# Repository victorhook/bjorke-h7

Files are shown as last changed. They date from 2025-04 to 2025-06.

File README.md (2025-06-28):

# 🛩️ Bjorke H7 Flight Controller

Bjorke H7 is a fully open source high-performance, ArduPilot-compatible flight controller built around the powerful STM32H743VIT6 MCU. Designed for flexibility and reliability, it supports a wide range of applications—from autonomous drones to experimental robotics.

---

## 🔧 Key Features

### ⚙️ Processing Power
- **MCU**: STM32H743VIT6 (480 MHz, 2MB Flash, 1MB RAM)

### 🧭 Sensors
- **IMU**: ICM-42688-P – ultra-low noise 6-axis motion tracking
- **Barometer**: BMP388 – high-accuracy altimeter for reliable altitude estimation

### 🔄 Interfaces & I/O
- **8x Motor Outputs** via 2x ESC 8-pin JST connectors
- **8x UARTs** for telemetry, GPS, companion computers, etc.
- **1x I²C** for external sensors or peripherals
- **3x Servo Outputs** + **1x dedicated GPIO**
- **1x RGB Status LED**
- **2x extra ADC Input Pins** for external sensors
- **1x CAN** (with onboard TJA1051TK/3 transceiver) – plug-and-play UAVCAN support

### 💾 Storage & Logging
- **MicroSD card slot** for robust onboard logging

### 🔌 Power Architecture
- **5V @ 3A** DC-DC
- **3.3V @ 3A** DC-DC

---

## ⚡ Designed for ArduPilot
Bjorke H7 runs **ArduPilot firmware** with support for:
- Real-time telemetry
- In-flight parameter updates
- MAVLink compatibility
- Full hardware-in-the-loop (HITL) testing
- CAN-based peripherals (UAVCAN GPS, ESCs, etc.)

---

## 🚧 Status
- [X] PCB rev.A designed and ordered
- [X] hwdef.dat
- [X] PCB rev.A hardware validated
- [X] Initial bring-up with ArduPilot firmware
- [X] Lua scripting verified
- [ ] First takeoff achieved
- [ ] 1 hour flight time achieved
- [ ] 5 hours flight time achieved
- [ ] 10 hours flight time achieved
- [ ] 25 hours flight time achieved
- [ ] 50 hours flight time achieved
- [ ] 100 hours flight time achieved

---

## 🧪 Ideal for:
- Custom drones (quads, hexas, octos)
- Research platforms
- Robotics
- Developers who need **max control and visibility**

## Flashing
With a fresh board we must flash the ardupilot bootloader. This requires us to put the mcu in DFU mode, which is done by holding down the boot button while powering on the board.

### Ardupilot + bootloader
1. Hold down boot button while powering on the board. If you're on linux you can use `dmesg -w` to monitor usb acitivty and you should get something like `Product: DFU in FS Mode` show up.
2. Open STM32CubeProgrammer and connect with USB
3. Open the file in `binaries/arducopter_with_bl.hex` and press flash
4. Powercycle the board and you should see `bjorke-BL` registers itself as USB device at first, then once it leaves bootloader you should get `bjorke` as USB device, and a serial port, eg `/dev/ttyACM0`

### Ardupilot application only
1. Using the `uploader.py` in AP repo
    ```
    python3 Tools/scripts/uploader.py build/bjorke/bin/arducopter.apj
    ```
2. Or, after built in repo: 
    ```
    ./waf copter --upload
    ```

### Ardupilot bootloader only
1. Put into DFU (same as above)
2. Flash bootloader using either STM32CubeProgrammer, or `dfu-util` with:
    ```
    dfu-util -a 0 --dfuse-address 0x08000000 -D binaries/AP_Bootloader.bin -R
    ```

### Building the code
Enter the ardupilot repository and run:

#### Bootloader
Either using:
```
./Tools/scripts/build_bootloaders.py bjorke
```
Creates binaries in `Tools/bootloaders/`:
- `Tools/bootloaders/bjorke_bl.bin`
- `Tools/bootloaders/bjorke_bl.hex`

Or, using:
```
./waf configure --board bjorke --bootloader
./waf clean
./waf bootloader
```

Bootloader binaries should be built to `build/bjorke/bin`
- AP_Bootloader.apj
- AP_Bootloader.bin
- AP_Bootloader.hex

#### Application
For the application build we first must have built bootloader with `./Tools/scripts/build_bootloaders.py`.
This is because AP tooling seems to expect a bootloader binary in `Tools/bootloaders/`.

```
./waf configure --board bjorke
./waf copter
```

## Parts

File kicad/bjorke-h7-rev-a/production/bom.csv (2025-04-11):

Designator | Footprint | Quantity | Value | LCSC Part #
C1 | 0402 | 1 | 4.7uF
C10, C12, C13, C19, C2, C20, C21, C23, C24, C28, C3, C32, C37, C5, C7, C8 | 0402 | 16 | 0.1uF
C11, C18, C9 | 0402 | 3 | 2.2uF
C14, C15, C34, C35 | 0805 | 4 | 10uF | C440198
C16, C36 | 0402 | 2 | 0.1uF | C307331
C17, C33, C38 | 0805 | 3 | 47uF | C16780
C22 | 0402 | 1 | 10nF
C39, C40 | 0402 | 2 | 15pF | C1548
C4, C6 | 0402 | 2 | 15pF
Card1 | TF-SMD_TF-021B-H265 | 1 | TF PUSH | C498185
D1 | 0603 | 1 | YELLOW
D2 | 0603 | 1 | BLUE
D3 | 0603 | 1 | GREEN
D4, D5, D7, D8 | D_SOD-323 | 4 | 30V 450mA | C2762697
D6 | 0603 | 1 | RED
J1 | Conn_2_Accesory_Bigger | 1 | Power_3V3
J10 | Conn_4_Accesory_Bigger | 1 | Servo 1-2
J11 | Conn_4_Accesory_Bigger | 1 | USART6
J12 | Conn_4_Accesory_Bigger | 1 | I2C
J13 | Conn_4_Accesory_Bigger_2x2 | 1 | UART8
J14 | Conn_3_2.54_SMD | 1 | Debug
J15 | Conn_3_Accesory_Bigger | 1 | RGB
J16 | CONN-TH_SM08B-SRSS-TB-LF-SN | 1 | FC-ESC 1 JST
J17 | Conn_4_Accesory_Bigger | 1 | UART5
J18 | CONN-TH_SM08B-SRSS-TB-LF-SN | 1 | FC-ESC 2 JST
J19 | Conn_8_Accesory | 1 | FC-ESC 2 Solder Pads Back
J2 | Conn_2_Accesory_Bigger | 1 | Power_5V
J20 | Conn_4_Accesory_Bigger | 1 | CAN
J21 | Conn_2_Accesory_Bigger | 1 | Power_VBAT
J22 | Conn_4_Accesory_Bigger | 1 | Servo5-GPIO1
J23, J24 | Conn_8_Accesory | 2 | FC-ESC 1 Solder Pads Front
J25 | Conn_3_Accesory_Bigger | 1 | Analog In
J26 | Conn_4_Accesory_Bigger | 1 | UART7
J3 | Conn_4_Accesory_Bigger | 1 | USART3
J4 | Conn_2_Accesory_Bigger | 1 | Power_4V5
J5 | Conn_8_Accesory | 1 | FC-ESC 1 Solder Pads Back
J6 | Conn_4_Accesory_Bigger_2x2 | 1 | USART2
J7 | Conn_4_Accesory_Bigger | 1 | USART1
J8 | Conn_4_Accesory_Bigger | 1 | Servo 3-4
J9 | Conn_4_Accesory_Bigger | 1 | UART4
L3, L4 | IND-SMD_L5.7-W5.2 | 2 | 6.8uH | C7461350
R10, R18, R6, R7, R8 | 0402 | 5 | 1k
R11, R2 | 0402 | 2 | 5.1k
R12, R13, R14, R15, R3, R4, R5, R9 | 0402 | 8 | 10k
R16 | 0402 | 1 | 120R
R17, R20, R21, R22 | 0402 | 4 | 2.2k
R23 | 0402 | 1 | 51k | C25794
R24, R26 | 0402 | 2 | 10k | C25744
R25 | 0402 | 1 | 30.9k | C185428
SW1 | SW-SMD_TS-1086EV-16 | 1 | SW_SPST
U2 | LQFP-100_14x14mm_P0.5mm | 1 | STM32H743VIT6
U3 | USB-SMD_GT-USB-7010AN | 1 | GT-USB-7010AN | C963370
U5 | SENSORM-SMD_BMP388 | 1 | BMP388 | C779278
U6 | LGA-14_L3.0-W2.5-P0.50-TL | 1 | ICM-42688-P | C1850418
U7 | HVSON-8-1EP_3x3mm_P0.65mm_EP1.6x2.4mm | 1 | TJA1051TK-3 | C2875699
U8, U9 | SOT-583-8_L2.1-W1.2-P0.50-LS1.6-BL | 2 | TPS563300DRLR | C5219249
Y1 | Crystal_SMD_2016-4Pin_2.0x1.6mm | 1 | 16 MHz | C2965579

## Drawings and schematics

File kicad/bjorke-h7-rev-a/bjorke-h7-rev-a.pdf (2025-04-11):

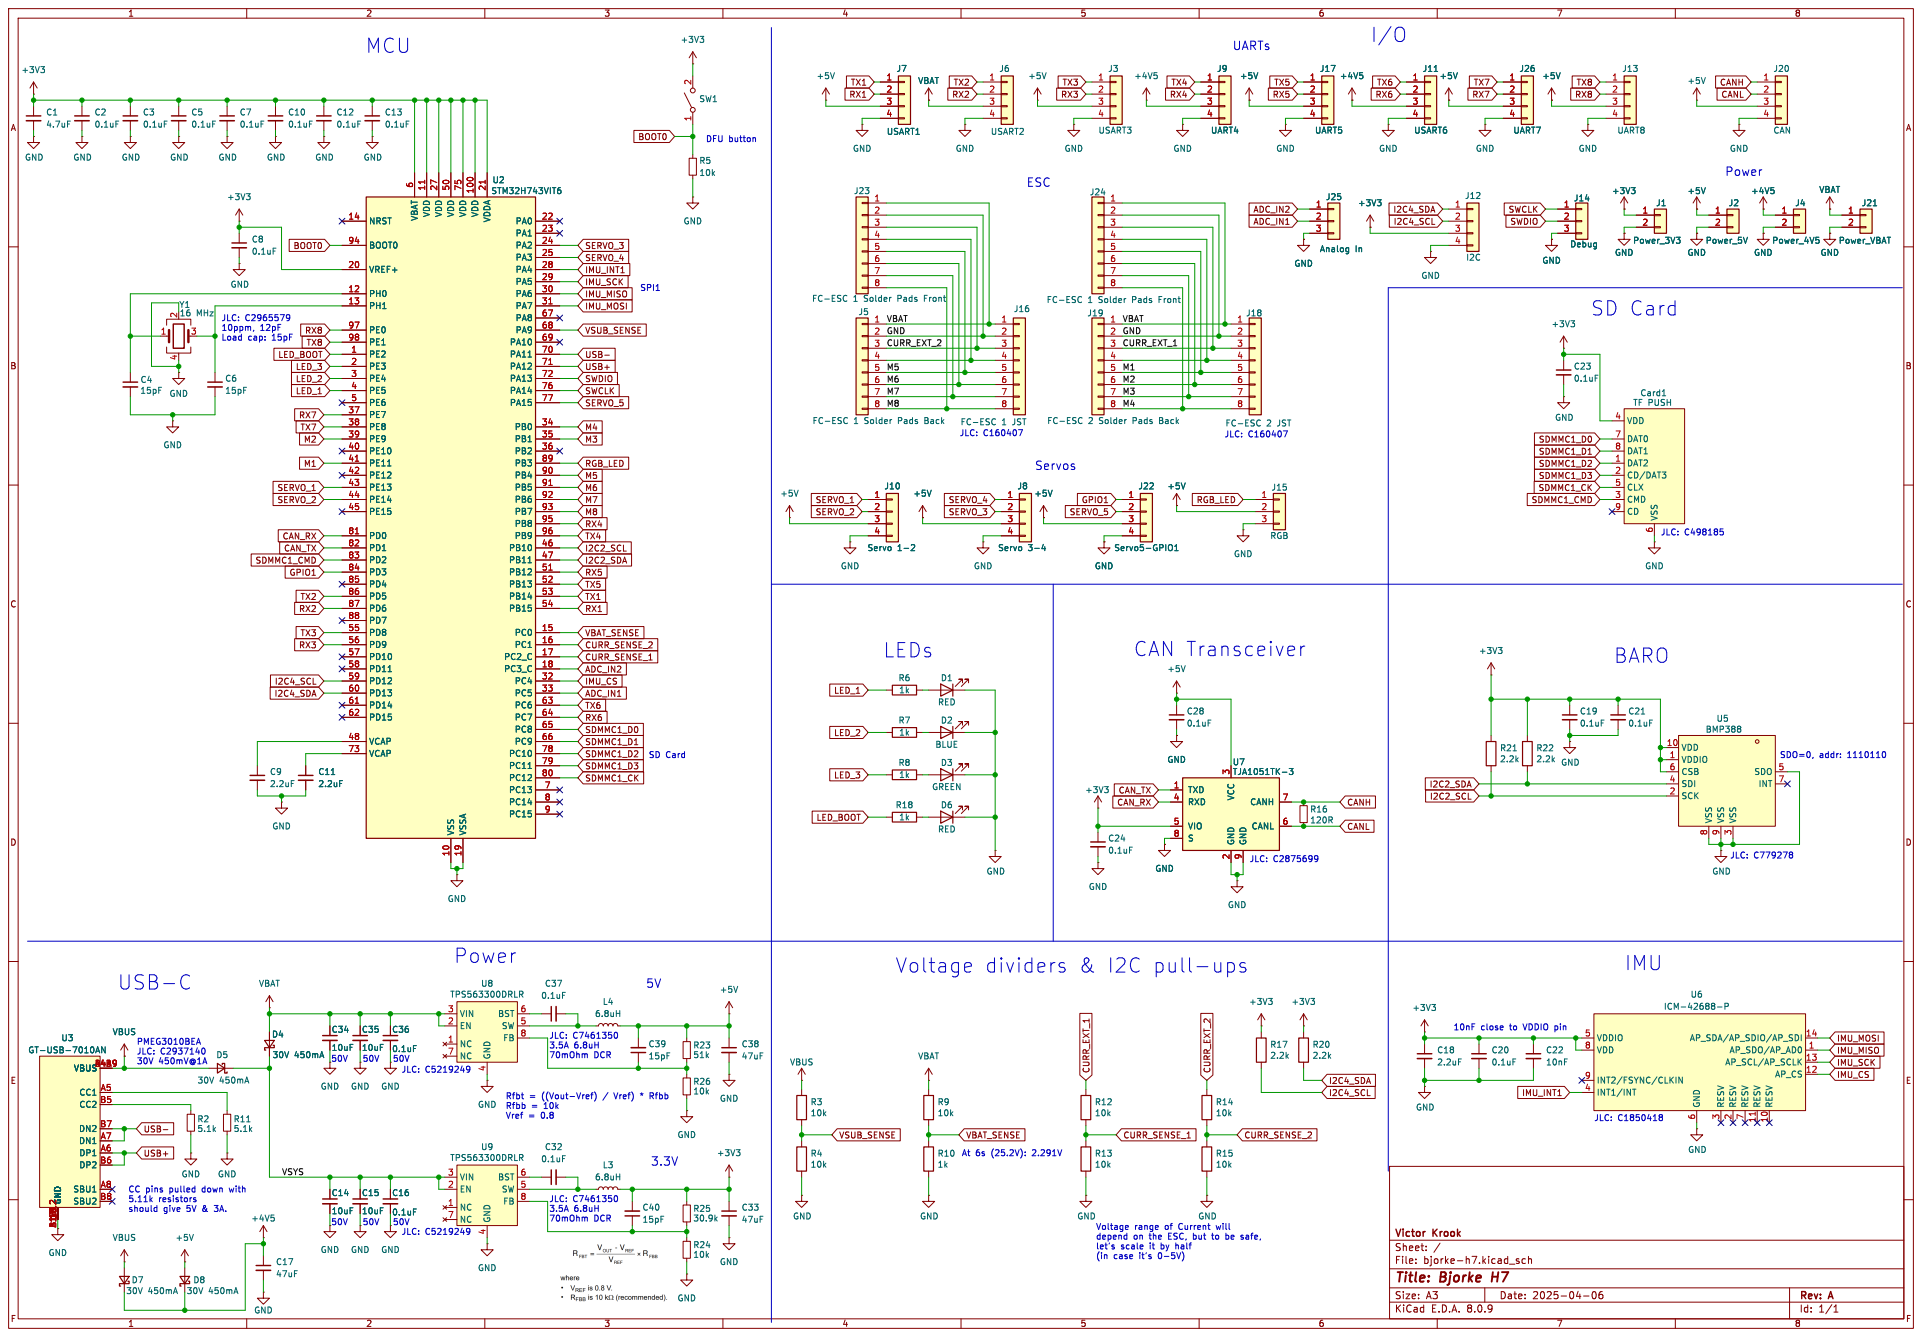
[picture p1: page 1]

J18 FC-ESC 2 JST GND

J24 FC-ESC 1 Solder Pads Front C2
0.1uF GND

J23 FC-ESC 1 Solder Pads Front 1

J19 FC-ESC 2 Solder Pads Back GND

J16 FC-ESC 1 JST GND

3 RXD 4 VIO 5 CANL 6 CANH 7 S

Voltage dividers & I2C pull-ups

4 SW 5 BST 6 FB 8 NC 1 NC 7 U8 TPS563300DRLR GND
+3V3 GND

10nF close to VDDIO pin

JLC: C1850418 CC pins pulled down with

4 SW 5 BST 6 FB 8 NC 1 NC 7 U9 TPS563300DRLR

GND
Voltage range of Current will depend on the ESC, but to be safe,

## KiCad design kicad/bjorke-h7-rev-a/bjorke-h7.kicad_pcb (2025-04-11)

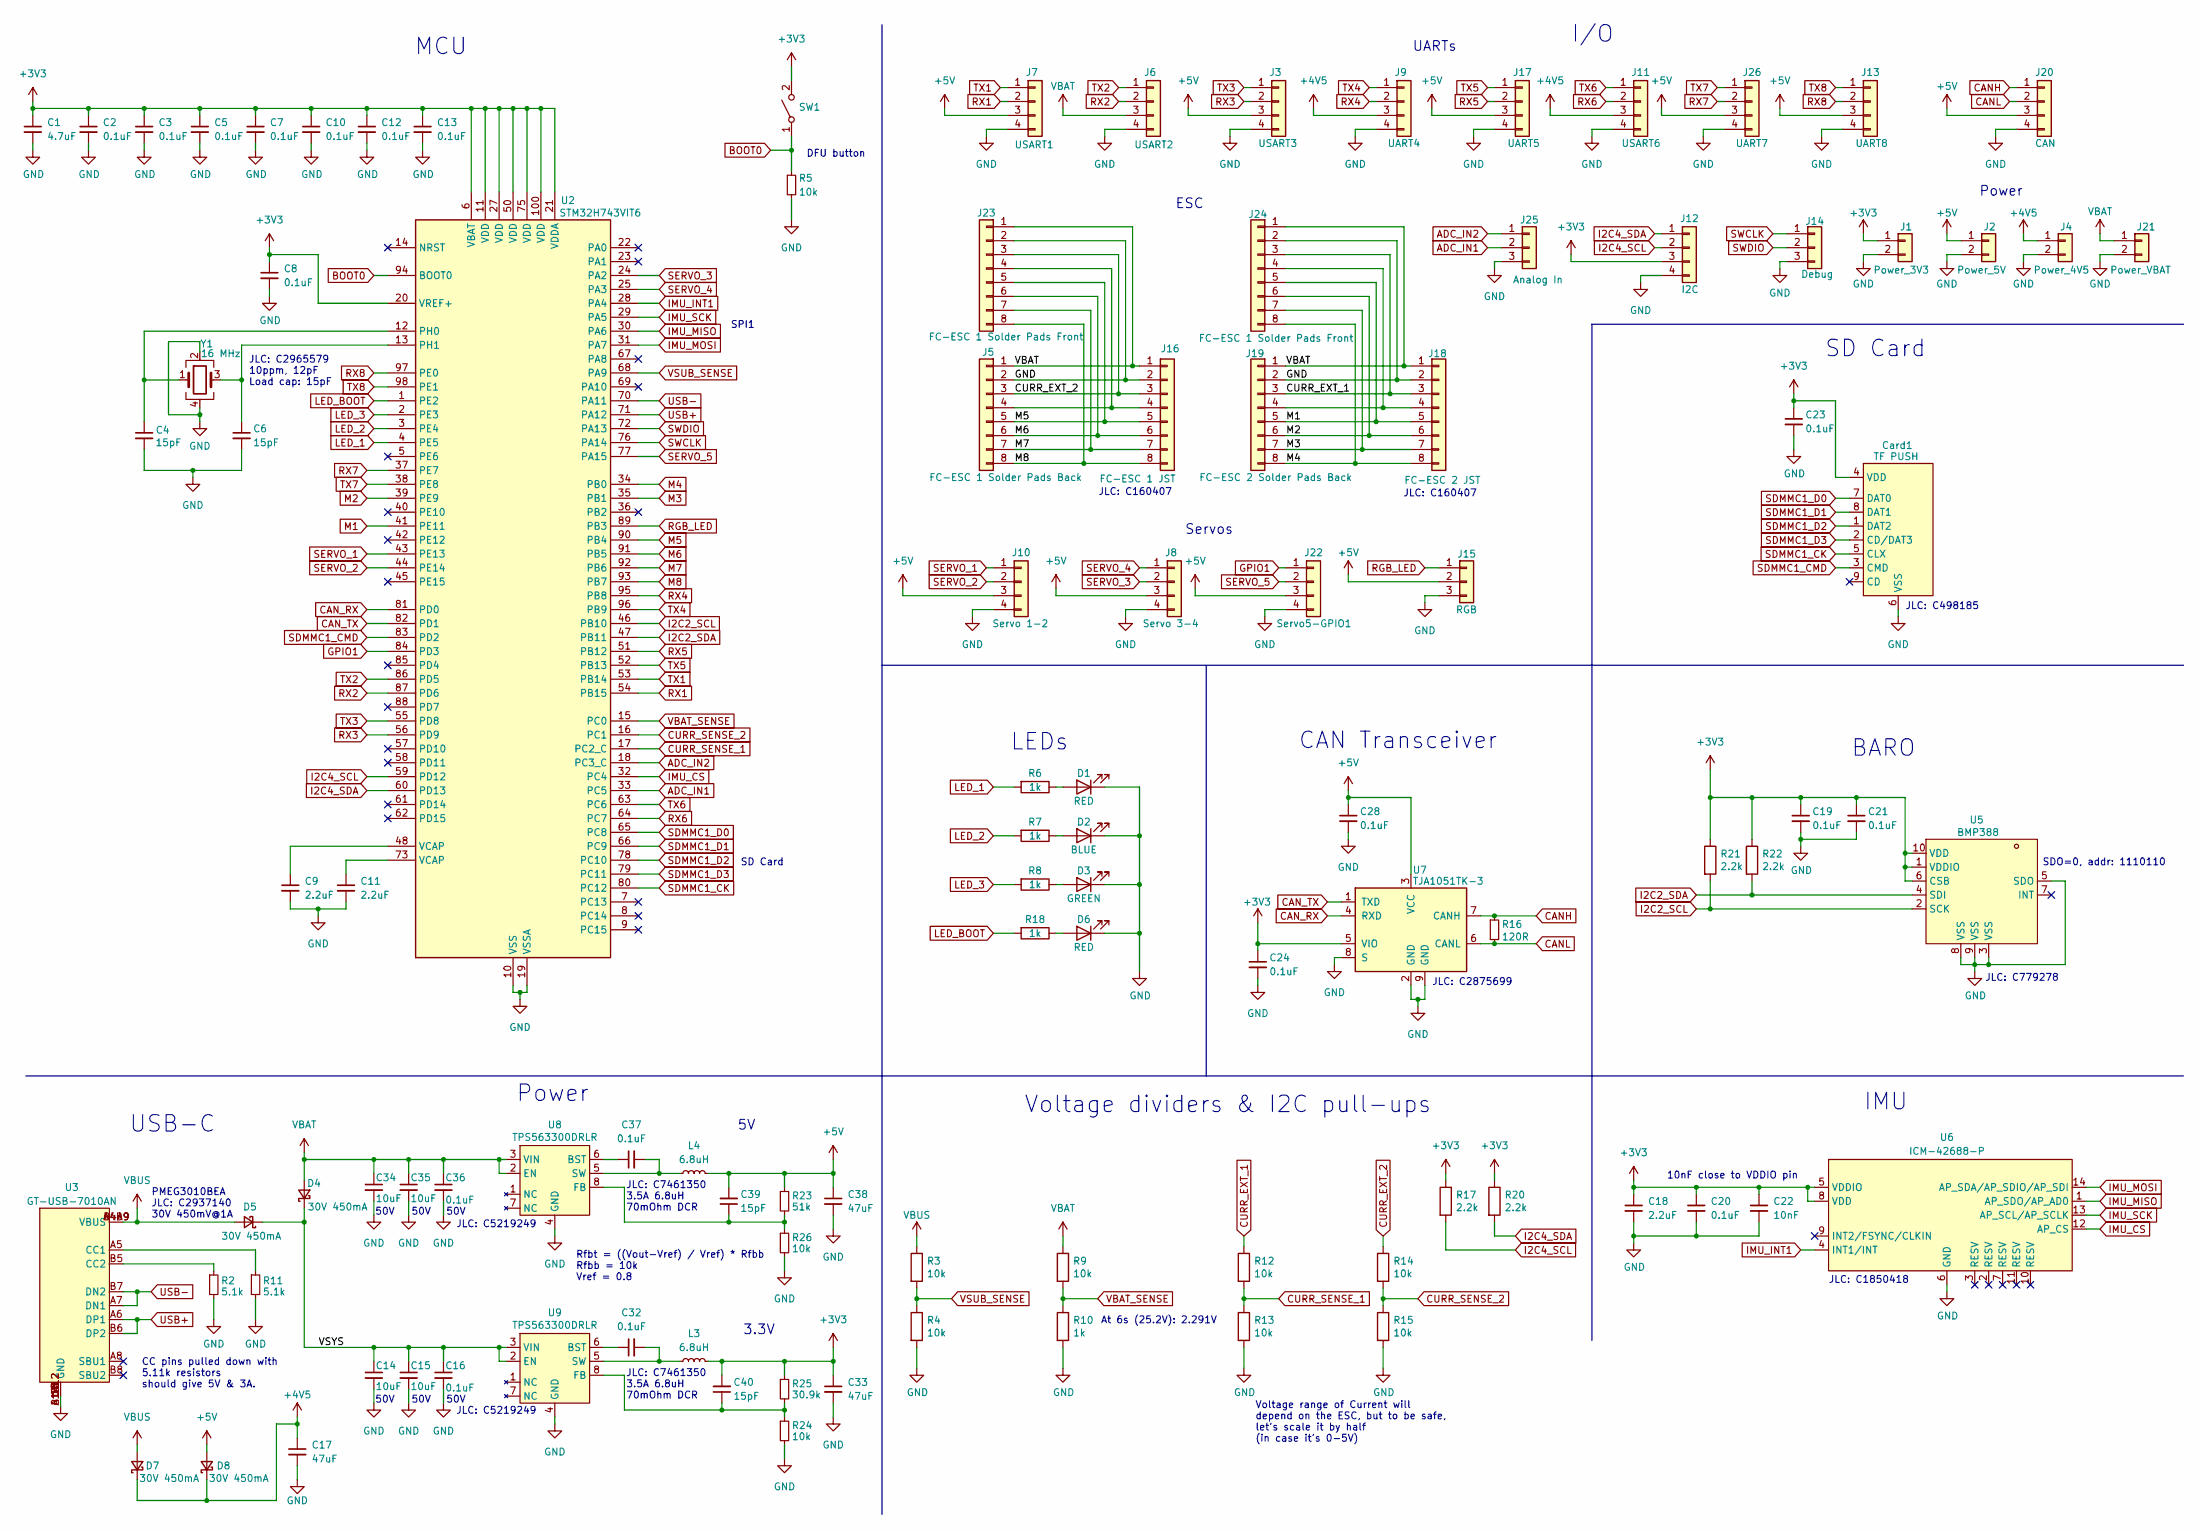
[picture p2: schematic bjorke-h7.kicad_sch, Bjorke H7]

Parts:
C1: 4.7uF; C_0402_1005Metric
C2, C3, C5, C7, C8, C10, C12, C13, C19, C20, C21, C23, C24, C28, C32, C37: 0.1uF; C_0402_1005Metric
C4, C6: 15pF; C_0402_1005Metric
C9, C11, C18: 2.2uF; C_0402_1005Metric
C14, C15, C34, C35: 10uF; C_0805_2012Metric; LCSC Part C440198
C16, C36: 0.1uF; C_0402_1005Metric; LCSC Part C307331
C17, C33, C38: 47uF; C_0805_2012Metric; LCSC Part C16780
C22: 10nF; C_0402_1005Metric
C39, C40: 15pF; C_0402_1005Metric; LCSC Part C1548
Card1: TF PUSH; TF-SMD_TF-021B-H265; LCSC Part C498185
D1, D6: RED; LED_0603_1608Metric
D2: BLUE; LED_0603_1608Metric
D3: GREEN; LED_0603_1608Metric
D4, D5, D7, D8: 30V 450mA; D_SOD-323; LCSC Part C2937140
J1: Power_3V3; Conn_2_Accesory_Bigger
J2: Power_5V; Conn_2_Accesory_Bigger
J3: USART3; Conn_4_Accesory_Bigger
J4: Power_4V5; Conn_2_Accesory_Bigger
J5: FC-ESC 1 Solder Pads Back; Conn_8_Accesory
J6: USART2; Conn_4_Accesory_Bigger_2x2
J7: USART1; Conn_4_Accesory_Bigger
J8: Servo 3-4; Conn_4_Accesory_Bigger
J9: UART4; Conn_4_Accesory_Bigger
J10: Servo 1-2; Conn_4_Accesory_Bigger
J11: USART6; Conn_4_Accesory_Bigger
J12: I2C; Conn_4_Accesory_Bigger
J13: UART8; Conn_4_Accesory_Bigger_2x2
J14: Debug; Conn_3_2.54_SMD
J15: RGB; Conn_3_Accesory_Bigger
J16: FC-ESC 1 JST; CONN-TH_SM08B-SRSS-TB-LF-SN
J17: UART5; Conn_4_Accesory_Bigger
J18: FC-ESC 2 JST; CONN-TH_SM08B-SRSS-TB-LF-SN
J19: FC-ESC 2 Solder Pads Back; Conn_8_Accesory
J20: CAN; Conn_4_Accesory_Bigger
J21: Power_VBAT; Conn_2_Accesory_Bigger
J22: Servo5-GPIO1; Conn_4_Accesory_Bigger
J23, J24: FC-ESC 1 Solder Pads Front; Conn_8_Accesory
J25: Analog In; Conn_3_Accesory_Bigger
J26: UART7; Conn_4_Accesory_Bigger
L3, L4: 6.8uH; IND-SMD_L5.7-W5.2; LCSC Part C7461350
R2, R11: 5.1k; R_0402_1005Metric
R3, R4, R5, R9, R12, R13, R14, R15: 10k; R_0402_1005Metric
R6, R7, R8, R10, R18: 1k; R_0402_1005Metric
R16: 120R; R_0402_1005Metric
R17, R20, R21, R22: 2.2k; R_0402_1005Metric
R23: 51k; R_0402_1005Metric; LCSC Part C25794
R24, R26: 10k; R_0402_1005Metric; LCSC Part C25744
R25: 30.9k; R_0402_1005Metric; LCSC Part C185428
SW1: SW_SPST; SW-SMD_TS-1086EV-16
U2: STM32H743VIT6; LQFP-100_14x14mm_P0.5mm
U3: GT-USB-7010AN; USB-SMD_GT-USB-7010AN; LCSC Part C963370
U5: BMP388; SENSORM-SMD_BMP388; LCSC Part C779278
U6: ICM-42688-P; LGA-14_L3.0-W2.5-P0.50-TL; LCSC Part C1850418
U7: TJA1051TK-3; HVSON-8-1EP_3x3mm_P0.65mm_EP1.6x2.4mm; LCSC Part C2875699
U8, U9: TPS563300DRLR; SOT-583-8_L2.1-W1.2-P0.50-LS1.6-BL; LCSC Part C5219249
Y1: 16 MHz; Crystal_SMD_2016-4Pin_2.0x1.6mm; LCSC Part C2965579

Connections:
+3V3: C1.1, C2.1, C3.1, C5.1, C7.1, C8.1, C10.1, C12.1, C13.1, C18.1, C19.1, C20.1, C21.1, C22.1, C23.1, C24.1, C33.1, C40.2, Card1.4 (VDD), J1.1, J12.3, L3.2, R17.1, R20.1, R21.1, R22.1, R25.1, SW1.2 (B), U2.6 (VBAT), U2.11 (VDD), U2.20 (VREF+), U2.21 (VDDA), U2.27 (VDD), U2.50 (VDD), U2.75 (VDD), U2.100 (VDD), U5.1 (VDDIO), U5.6 (CSB), U5.10 (VDD), U6.5 (VDDIO), U6.8 (VDD), U7.5 (VIO)
+4V5: C17.1, D7.1 (K), D8.1 (K), J4.1, J9.3, J11.3
+5V: C28.1, C38.1, C39.2, D8.2 (A), J2.1, J3.3, J7.3, J8.3, J10.3, J13.3, J15.2, J17.3, J20.3, J22.3, J26.3, L4.2, R23.1, U7.3 (VCC)
/VSYS: C14.1, C15.1, C16.1, D4.1 (K), D5.1 (K), U9.2 (EN), U9.3 (VIN)
ADC_IN1: J25.2, U2.33 (PC5)
ADC_IN2: J25.1, U2.18 (PC3_C)
BOOT0: R5.1, SW1.1 (A), U2.94 (BOOT0)
CANH: J20.1, R16.1, U7.7 (CANH)
CANL: J20.2, R16.2, U7.6 (CANL)
CAN_RX: U2.81 (PD0), U7.4 (RXD)
CAN_TX: U2.82 (PD1), U7.1 (TXD)
CURR_EXT_1: J18.3, J19.3, J24.3, R12.1
CURR_EXT_2: J5.3, J16.3, J23.3, R14.1
CURR_SENSE_1: R12.2, R13.1, U2.17 (PC2_C)
CURR_SENSE_2: R14.2, R15.1, U2.16 (PC1)
GND: C1.2, C2.2, C3.2, C4.2, C5.2, C6.2, C7.2, C8.2, C9.2, C10.2, C11.2, C12.2, C13.2, C14.2, C15.2, C16.2, C17.2, C18.2, C19.2, C20.2, C21.2, C22.2, C23.2, C24.2, C28.2, C33.2, C34.2, C35.2, C36.2, C38.2, Card1.6 (VSS), D1.1 (K), D2.1 (K), D3.1 (K), D6.1 (K), J1.2, J2.2, J3.4, J4.2, J5.2, J6.4, J7.4, J8.4, J9.4, J10.4, J11.4, J12.4, J13.4, J14.3, J15.3, J16.2, J17.4, J18.2, J19.2, J20.4, J21.2, J22.4, J23.2, J24.2, J25.3, J26.4, R2.2, R4.2, R5.2, R10.2, R11.2, R13.2, R15.2, R24.2, R26.2, U2.10 (VSS), U2.19 (VSSA), U2.26 (VSS), U2.49 (VSS), U2.74 (VSS), U2.99 (VSS), U3.13 (GND), U3.14 (GND), U3.15 (GND), U3.16 (GND), U3.A1B12 (GND), U3.B1A12 (GND), U5.3 (VSS), U5.5 (SDO), U5.8 (VSS), U5.9 (VSS), U6.6 (GND), U7.2 (GND), U7.8 (S), U7.9 (GND), U8.4 (GND), U9.4 (GND), Y1.2, Y1.4
GPIO1: J22.1, U2.84 (PD3)
I2C2_SCL: R21.2, U2.46 (PB10), U5.2 (SCK)
I2C2_SDA: R22.2, U2.47 (PB11), U5.4 (SDI)
I2C4_SCL: J12.2, R17.2, U2.59 (PD12)
I2C4_SDA: J12.1, R20.2, U2.60 (PD13)
IMU_CS: U2.32 (PC4), U6.12 (AP_CS)
IMU_INT1: U2.28 (PA4), U6.4 (INT1/INT)
IMU_MISO: U2.30 (PA6), U6.1 (AP_SDO/AP_AD0)
IMU_MOSI: U2.31 (PA7), U6.14 (AP_SDA/AP_SDIO/AP_SDI)
IMU_SCK: U2.29 (PA5), U6.13 (AP_SCL/AP_SCLK)
LED_1: R6.2, U2.4 (PE5)
LED_2: R7.2, U2.3 (PE4)
LED_3: R8.2, U2.2 (PE3)
LED_BOOT: R18.2, U2.1 (PE2)
M1: J18.5, J19.5, J24.5, U2.41 (PE11)
M2: J18.6, J19.6, J24.6, U2.39 (PE9)
M3: J18.7, J19.7, J24.7, U2.35 (PB1)
M4: J18.8, J19.8, J24.8, U2.34 (PB0)
M5: J5.5, J16.5, J23.5, U2.90 (PB4)
M6: J5.6, J16.6, J23.6, U2.91 (PB5)
M7: J5.7, J16.7, J23.7, U2.92 (PB6)
M8: J5.8, J16.8, J23.8, U2.93 (PB7)
unnamed: C9.1, U2.48 (VCAP)
unnamed: C11.1, U2.73 (VCAP)
unnamed: D1.2 (A), R6.1
unnamed: D2.2 (A), R7.1
unnamed: D3.2 (A), R8.1
unnamed: D6.2 (A), R18.1
unnamed: J5.4, J16.4, J23.4
unnamed: J18.4, J19.4, J24.4
unnamed: C4.1, U2.12 (PH0), Y1.1
unnamed: C6.1, U2.13 (PH1), Y1.3
unnamed: R11.1, U3.A5 (CC1)
unnamed: R2.1, U3.B5 (CC2)
unnamed: C37.1, U8.6 (BST)
unnamed: C39.1, R23.2, R26.1, U8.8 (FB)
unnamed: C37.2, L4.1, U8.5 (SW)
unnamed: C32.1, U9.6 (BST)
unnamed: C40.1, R24.1, R25.2, U9.8 (FB)
unnamed: C32.2, L3.1, U9.5 (SW)
RGB_LED: J15.1, U2.89 (PB3)
RX1: J7.2, U2.54 (PB15)
RX2: J6.2, U2.87 (PD6)
RX3: J3.2, U2.56 (PD9)
RX4: J9.2, U2.95 (PB8)
RX5: J17.2, U2.51 (PB12)
RX6: J11.2, U2.64 (PC7)
RX7: J26.2, U2.37 (PE7)
RX8: J13.2, U2.97 (PE0)
SDMMC1_CK: Card1.5 (CLX), U2.80 (PC12)
SDMMC1_CMD: Card1.3 (CMD), U2.83 (PD2)
SDMMC1_D0: Card1.7 (DAT0), U2.65 (PC8)
SDMMC1_D1: Card1.8 (DAT1), U2.66 (PC9)
SDMMC1_D2: Card1.1 (DAT2), U2.78 (PC10)
SDMMC1_D3: Card1.2 (CD/DAT3), U2.79 (PC11)
SERVO_1: J10.1, U2.43 (PE13)
SERVO_2: J10.2, U2.44 (PE14)
SERVO_3: J8.2, U2.24 (PA2)
SERVO_4: J8.1, U2.25 (PA3)
SERVO_5: J22.2, U2.77 (PA15)
SWCLK: J14.1, U2.76 (PA14)
SWDIO: J14.2, U2.72 (PA13)
TX1: J7.1, U2.53 (PB14)
TX2: J6.1, U2.86 (PD5)
TX3: J3.1, U2.55 (PD8)
TX4: J9.1, U2.96 (PB9)
TX5: J17.1, U2.52 (PB13)
TX6: J11.1, U2.63 (PC6)
TX7: J26.1, U2.38 (PE8)
TX8: J13.1, U2.98 (PE1)
USB+: U2.71 (PA12), U3.A6 (DP1), U3.B6 (DP2)
USB-: U2.70 (PA11), U3.A7 (DN1), U3.B7 (DN2)
VBAT: C34.1, C35.1, C36.1, D4.2 (A), J5.1, J6.3, J16.1, J18.1, J19.1, J21.1, J23.1, J24.1, R9.1, U8.2 (EN), U8.3 (VIN)
VBAT_SENSE: R9.2, R10.1, U2.15 (PC0)
VBUS: D5.2 (A), D7.2 (A), R3.1, U3.A4B9 (VBUS), U3.B4A9 (VBUS)
VSUB_SENSE: R3.2, R4.1, U2.68 (PA9)

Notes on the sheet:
JLC: C5219249
Voltage dividers & I2C pull-ups
JLC: C2965579 10ppm, 12pF Load cap: 15pF
At 6s (25.2V): 2.291V
50V
SD Card
I/O
JLC: C160407
JLC: C498185
Voltage range of Current will depend on the ESC, but to be safe, let's scale it by half (in case it's 0-5V)
LEDs
ESC
IMU
JLC: C1850418
JLC: C7461350 3.5A 6.8uH 70mOhm DCR
BARO
DFU button
UARTs
10nF close to VDDIO pin
JLC: C779278
JLC: C2875699
3.3V
SDO=0, addr: 1110110
CC pins pulled down with 5.11k resistors should give 5V & 3A.
USB-C
Power
Servos
PMEG3010BEA JLC: C2937140 30V 450mV@1A
SPI1
CAN Transceiver
Rfbt = ((Vout-Vref) / Vref) * Rfbb Rfbb = 10k Vref = 0.8
MCU

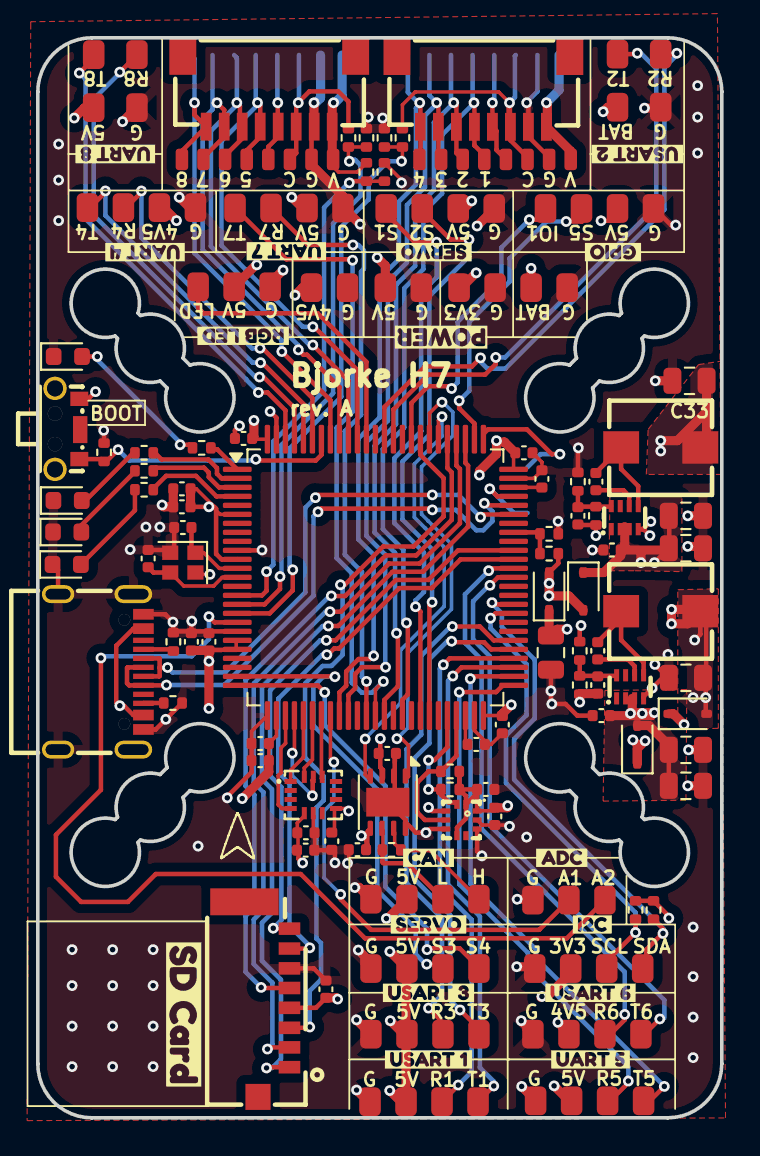
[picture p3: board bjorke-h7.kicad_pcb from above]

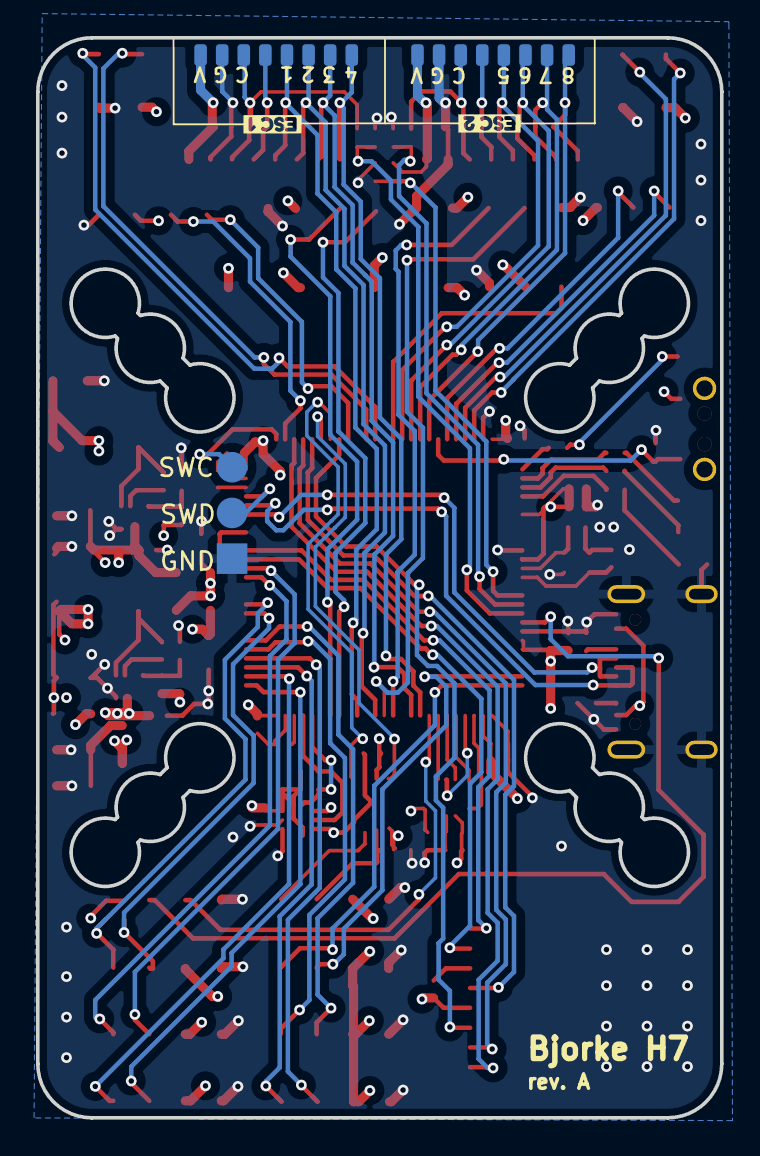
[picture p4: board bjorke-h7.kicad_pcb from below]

Board: 4 copper layers, 38.0 x 60.0 mm, 123 parts (5 on the bottom side), 92 nets.

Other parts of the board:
kibuzzard-67DE5AB0: G***; kibuzzard-67DE5AB0
kibuzzard-67DE5AD0: G***; kibuzzard-67DE5AD0
kibuzzard-67DE5AF3: G***; kibuzzard-67DE5AF3
kibuzzard-67DE5B23: G***; kibuzzard-67DE5B23
kibuzzard-67DE5B50: G***; kibuzzard-67DE5B50
kibuzzard-67DE5E84: G***; kibuzzard-67DE5E84
kibuzzard-67DE5E92: G***; kibuzzard-67DE5E92
kibuzzard-67DE57A5: G***; kibuzzard-67DE57A5
kibuzzard-67DE59DE: G***; kibuzzard-67DE59DE
kibuzzard-67DE573A: G***; kibuzzard-67DE573A
kibuzzard-67DE5740: G***; kibuzzard-67DE5740
kibuzzard-67DE5922: G***; kibuzzard-67DE5922
kibuzzard-67E2C95F: G***; kibuzzard-67E2C95F
kibuzzard-67EA1A9D: G***; kibuzzard-67EA1A9D
kibuzzard-67EA1ABB: G***; kibuzzard-67EA1ABB
kibuzzard-67EA1AD2: G***; kibuzzard-67EA1AD2
kibuzzard-67EA1AE5: G***; kibuzzard-67EA1AE5
kibuzzard-67EE0EFE: G***; kibuzzard-67EE0EFE
kibuzzard-67EE0F1B: G***; kibuzzard-67EE0F1B

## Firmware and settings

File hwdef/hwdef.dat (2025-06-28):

# hw definition file for processing by chibios_hwdef.py
# for bjorke H743

# MCU class and specific type (STM32H743VIT6)
MCU STM32H7xx STM32H743xx

# board ID for firmware load
APJ_BOARD_ID 1337

# crystal frequency, setup to use external oscillator
OSCILLATOR_HZ 16000000

FLASH_SIZE_KB 2048

# supports upto 8MBits/s
CANFD_SUPPORTED 8

# with 2M flash we can afford to optimize for speed
env OPTIMIZE -Os

# bootloader takes first sector
FLASH_RESERVE_START_KB 128

# Enable FLASH parameter storage.
define HAL_STORAGE_SIZE 32768
define STORAGE_FLASH_PAGE 14

STM32_ST_USE_TIMER 5

# These are the pins for SWD debugging with a STlinkv2 or black-magic probe.
PA13 JTMS-SWDIO SWD
PA14 JTCK-SWCLK SWD

# -- USB -- #
USB_STRING_MANUFACTURER "bjorke"

# USB
PA11 OTG_FS_DM OTG1
PA12 OTG_FS_DP OTG1

# OTG USB VBUS (USB detect)
PA9 VBUS INPUT

# -- SPI devices -- ##
SPIDEV icm42688  SPI1 DEVID1 IMU_CS    MODE3 2*MHZ 16*MHZ

# SPI1 for ICM-42688-P IMU
PA5 SPI1_SCK  SPI1
PA6 SPI1_MISO SPI1
PA7 SPI1_MOSI SPI1
PC4 IMU_CS    CS

# pins for SD card:
PC8  SDMMC1_D0 SDMMC1
PC9  SDMMC1_D1 SDMMC1
PC10 SDMMC1_D2 SDMMC1
PC11 SDMMC1_D3 SDMMC1
PC12 SDMMC1_CK SDMMC1
PD2  SDMMC1_CMD SDMMC1

# -- SERIAL ports -- #
# order of UARTs (and USB) - Add OTG2 to this list if you want SLCAN on USB too
SERIAL_ORDER OTG1 USART1 USART2 USART3 UART4 UART5 USART6 UART7 UART8

# default the 2nd interface to SLCAN
#define HAL_OTG2_PROTOCOL SerialProtocol_SLCAN

# USART1
PB14 USART1_TX USART1
PB15 USART1_RX USART1

# USART2
PD5 USART2_TX USART2
PD6 USART2_RX USART2

# USART3
PD8 USART3_TX USART3
PD9 USART3_RX USART3

# UART4
PB9 UART4_TX UART4 NODMA
PB8 UART4_RX UART4 NODMA

# UART5
PB13 UART5_TX UART5 NODMA
PB12 UART5_RX UART5 NODMA

# USART6
PC6 USART6_TX USART6
PC7 USART6_RX USART6

# UART7
PE8 UART7_TX UART7
PE7 UART7_RX UART7

# UART8
PE1 UART8_TX UART8
PE0 UART8_RX UART8

# -- I2C ports -- #
I2C_ORDER I2C2 I2C4

# I2C2
PB10 I2C2_SCL I2C2
PB11 I2C2_SDA I2C2

# I2C4
PD12 I2C4_SCL I2C4
PD13 I2C4_SDA I2C4

# -- CAN -- #
PD1 CAN1_TX CAN1
PD0 CAN1_RX CAN1

# -- ADC ports -- #
define HAL_BATT_MONITOR_DEFAULT 4

# Voltage
PC0 BATT_VOLTAGE_SENS ADC1 SCALE(1)
define HAL_BATT_VOLT_PIN 11
define HAL_BATT_VOLT_SCALE 11.0

# Current 1
PC2 BATT_CURRENT_SENS ADC1 SCALE(1)
define HAL_BATT_CURR_PIN 8
define HAL_BATT_CURR_SCALE 70.8

# Current 2
PC1 BATT_CURRENT_SENS2 ADC1 SCALE(1)
define HAL_BATT2_CURR_PIN 10
define HAL_BATT2_CURR_SCALE 10

# -- MOTORS -- #
PE11 TIM1_CH2  TIM1  PWM(1) GPIO(101) # M1
PE9  TIM1_CH1  TIM1  PWM(2) GPIO(102) # M2
PB1  TIM3_CH4  TIM3  PWM(3) GPIO(103) # M3
PB0  TIM3_CH3  TIM3  PWM(4) GPIO(104) # M4
PB4  TIM3_CH1  TIM3  PWM(5) GPIO(105) # M5
PB5  TIM3_CH2  TIM3  PWM(6) GPIO(106) # M6
PB6  TIM4_CH1  TIM4  PWM(7) GPIO(107) # M7
PB7  TIM4_CH2  TIM4  PWM(8) GPIO(108) # M8

# -- Servos -- #
PE13 TIM1_CH3  TIM1  PWM(9)  GPIO(50) NODMA # S1
PE14 TIM1_CH4  TIM1  PWM(10) GPIO(51) NODMA # S2
PA2  TIM15_CH1 TIM15 PWM(11) GPIO(52) NODMA # S3
PA3  TIM15_CH2 TIM15 PWM(11) GPIO(53) NODMA # S4
PA15 TIM2_CH1  TIM2  PWM(11) GPIO(54) NODMA # S5

# -- RGB LED strip -- #
PB3  TIM2_CH2  TIM2  PWM(12) GPIO(55)

# -- AUX GPIO -- #
PD3 GPIO1 OUTPUT LOW GPIO(56)

# -- AUX ADC -- #
PC5 ADC_IN1 ADC1 SCALE(2)
PC3 ADC_IN2 ADC1 SCALE(2)

# -- LEDs -- #
PE3 LED0 OUTPUT LOW GPIO(90) # White
PE4 LED1 OUTPUT LOW GPIO(91) # Blue
PE5 LED2 OUTPUT LOW GPIO(92) # Red
define AP_NOTIFY_GPIO_LED_1_ENABLED 1
define AP_NOTIFY_GPIO_LED_1_PIN 91
define HAL_GPIO_A_LED_PIN 90
define HAL_GPIO_B_LED_PIN 91
define HAL_GPIO_C_LED_PIN 92

# -- OSD -- #
define HAL_OSD_TYPE_DEFAULT 1
ROMFS_WILDCARD libraries/AP_OSD/fonts/font*.bin

# -- BARO -- #
define AP_BARO_BACKEND_DEFAULT_ENABLED 0
define AP_BARO_BMP388_ENABLED 1
BARO BMP388 I2C:0:0x76

# -- IMU -- #
IMU Invensensev3 SPI:icm42688 ROTATION_ROLL_180_YAW_90

# DMA_PRIORITY
DMA_NOSHARE SPI1

# no built-in compass, but probe the i2c bus for all possible
# external compass types
define ALLOW_ARM_NO_COMPASS 1
define HAL_PROBE_EXTERNAL_I2C_COMPASSES 1
define HAL_I2C_INTERNAL_MASK 0

# filesystem setup on sdcard
define HAL_OS_FATFS_IO 1
# define AP_BOOTLOADER_FLASH_FROM_SD_ENABLED 1

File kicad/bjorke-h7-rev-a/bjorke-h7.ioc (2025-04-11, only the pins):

Mcu.UserName=STM32H743VITx
PA11.Signal=USB_OTG_FS_DM
PA12.Signal=USB_OTG_FS_DP
PA2.GPIO_Label=SERVO3
PA2.Signal=S_TIM15_CH1
PA3.GPIO_Label=SERVO4
PA3.Signal=S_TIM15_CH2
PA4.GPIO_Label=IMU_INT
PA4.Signal=GPIO_Input
PA5.GPIO_Label=IMU_SCK
PA5.Signal=SPI1_SCK
PA6.GPIO_Label=IMU_MISO
PA6.Signal=SPI1_MISO
PA7.GPIO_Label=IMU_MOSI
PA7.Signal=SPI1_MOSI
PA9.Signal=USB_OTG_FS_VBUS
PB0.GPIO_Label=M4
PB0.Signal=S_TIM3_CH3
PB1.GPIO_Label=M3
PB1.Signal=S_TIM3_CH4
PB10.Signal=I2C2_SCL
PB11.Signal=I2C2_SDA
PB12.Signal=UART5_RX
PB13.Signal=UART5_TX
PB14.Signal=USART1_TX
PB15.Signal=USART1_RX
PB5.GPIO_Label=M6
PB5.Signal=S_TIM3_CH2
PB6.GPIO_Label=M7
PB6.Signal=S_TIM4_CH1
PB7.GPIO_Label=M8
PB7.Signal=S_TIM4_CH2
PB8.Signal=UART4_RX
PB9.Signal=UART4_TX
PC0.GPIO_Label=VBAT_SENSE
PC0.Signal=ADCx_INP10
PC1.GPIO_Label=CURRENT_SENSE_2
PC1.Signal=ADCx_INP11
PC10.Signal=SDMMC1_D2
PC11.Signal=SDMMC1_D3
PC12.Signal=SDMMC1_CK
PC2_C.GPIO_Label=CURRENT_SENSE_1
PC2_C.Signal=ADC3_INP0
PC3_C.GPIO_Label=ADC_IN2
PC3_C.Signal=ADC3_INP1
PC4.GPIO_Label=IMU_CS
PC4.Signal=GPIO_Output
PC5.GPIO_Label=ADC_IN1
PC5.Signal=ADCx_INP8
PC6.Signal=USART6_TX
PC7.Signal=USART6_RX
PC8.Signal=SDMMC1_D0
PC9.Signal=SDMMC1_D1
PD0.Signal=FDCAN1_RX
PD1.Signal=FDCAN1_TX
PD12.Signal=I2C4_SCL
PD13.Signal=I2C4_SDA
PD2.Signal=SDMMC1_CMD
PD3.GPIO_Label=GPIO1
PD3.Signal=GPIO_Output
PD5.Signal=USART2_TX
PD6.Signal=USART2_RX
PD8.Signal=USART3_TX
PD9.Signal=USART3_RX
PE0.Signal=UART8_RX
PE1.Signal=UART8_TX
PE11.GPIO_Label=M1
PE11.Signal=S_TIM1_CH2
PE13.GPIO_Label=SERVO1
PE13.Signal=S_TIM1_CH3
PE14.GPIO_Label=SERVO2
PE14.Signal=S_TIM1_CH4
PE2.GPIO_Label=LED_BOOT
PE2.Signal=GPIO_Output
PE3.GPIO_Label=LED_3
PE3.Signal=GPIO_Output
PE4.GPIO_Label=LED_1
PE4.Signal=GPIO_Output
PE5.GPIO_Label=LED_2
PE5.Signal=GPIO_Output
PE7.Signal=UART7_RX
PE8.Signal=UART7_TX
PE9.GPIO_Label=M2
PE9.Signal=S_TIM1_CH1

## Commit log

2025-04-11 Initial commit, rev.A ordered
    [bjorke-h7.kicad_pcb, bjorke-h7.kicad_sch, bom.csv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]
2025-06-28 Added 3d model of pcb
2025-06-28 First working firmware!
    Built on `master` on AP, commit `aee973f4de9ce570d5302ab00cd72f2b8c6daece`.
    [defaults.parm]
